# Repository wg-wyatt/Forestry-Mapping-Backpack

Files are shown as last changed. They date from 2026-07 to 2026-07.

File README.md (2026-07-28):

# Forestry Mapping Backpack

<table align="center" width="100%">
  <tr>
    <td align="center" valign="middle" width="50%">
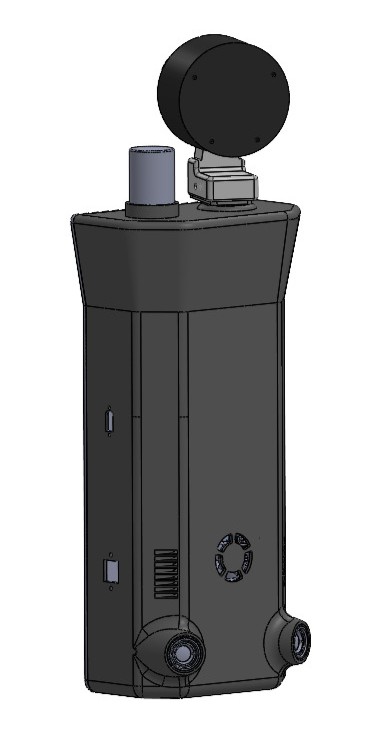
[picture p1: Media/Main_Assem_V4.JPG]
Forestry Mapping Backpack Exterior
      
      <br>
      <b>Exterior Assembly</b>
    </td>
    <td align="center" valign="middle" width="50%">
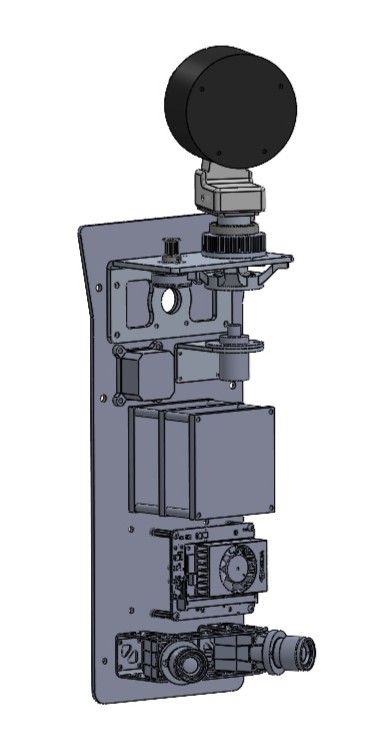
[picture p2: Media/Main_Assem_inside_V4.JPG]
Forestry Mapping Backpack Interior
      
      <br>
      <b>Interior Assembly</b>
    </td>
  </tr>
</table>

---

## Overview
The LiDAR Backpack Mapping System is a mobile, human-wearable sensing platform engineered to improve 3D point cloud density and spatial coverage for forestry and ecological surveying. Developed to replace rigid mast-mounted sensors, the system integrates a continuous secondary rotation axis with onboard processing to optimize sensor range, lower the user's center of gravity, and improve ergonomics during extended field deployment.

---

## Key Features

- Rotating LiDAR platform
- Integrated IMU for spatial orientation
- Modular mechanical architecture
- MATLAB analysis supporting point cloud generation
- Timing belt-driven rotation system
- Custom KiCad PCB
- FEA-validated structural design
- Optimized for low-volume manufacturing

### Project Disclaimer

This project was completed in collaboration with the Purdue Forestry Department. Certain project details, files, and implementation documentation may be limited due to sponsor requirements and intellectual property considerations.

---

## Problem Statement
The Purdue Forestry Department utilizes a machine learning–based plant recognition system to assist researchers with ecological surveying and vegetation analysis. Their legacy setup relied on a static LiDAR sensor mounted atop a tall backpack support mast. This configuration suffered from two major limitations:
* **Limited Spatial Coverage:** The static sensor depended entirely on natural user motion during field traversal to expand scan coverage, leading to low point cloud density and occlusions.
* **Poor Ergonomics:** Positioning significant mass high above the backpack shifted the system's center of gravity, reducing stability and user comfort during extended hiking over uneven terrain.

The objective of this project was to engineer a field-deployable mounting platform that adds a continuous secondary rotation axis to maximize point cloud density while relocating system mass closer to the user's center of gravity.

---

## Design Requirements

The following design requirements were established during the concept development phase to guide system architecture and engineering decisions. Requirements were selected to balance field usability, sensing performance, manufacturability, and compatibility with the existing Purdue Forestry Department backpack platform.

### Mechanical Requirements

| ID | Requirement | Target | Verification Method |
|----|---|---|---|
| DR-01 | Total system weight | < 10 kg (excluding backpack) | CAD mass properties |
| DR-02 | Structural durability | Withstand 5 g loading without structural failure | Finite Element Analysis (FEA) |
| DR-03 | Manufacturability | Components shall be manufacturable using conventional CNC machining, sheet metal fabrication, additive manufacturing, and commercially available hardware | Design review and manufacturing drawings |
| DR-04 | Serviceability | Electronics and wearable components shall be removable without permanent modification to the assembly | Assembly review |

### Functional Requirements

| ID | Requirement | Target | Verification Method |
|----|---|---|---|
| FR-01 | Point cloud coverage | Provide 360° scanning with a secondary axis of rotation to improve spatial coverage and reduce occlusions | MATLAB analysis and future field validation |
| FR-02 | Rotational position tracking | Report motor position to ±0.01° for point cloud reconstruction | Encoder specification and software verification |

### Integration Requirements

| ID | Requirement | Target | Verification Method |
|----|---|---|---|
| IR-01 | Backpack compatibility | Integrate with the existing Purdue Forestry backpack frame, 24 V hot-swappable M18 battery system, and existing data interfaces | CAD integration and electrical design review |
| IR-02 | Environmental protection | Minimum enclosure protection equivalent to IP32 | Enclosure design review and future ingress testing |

---

## System Architecture

The LiDAR Backpack Mapping System is a modular mechatronic platform structured into four core subsystems: **Sensing**, **Motion Control**, **Power Distribution**, and **Processing & Data**. 

<p align="center">
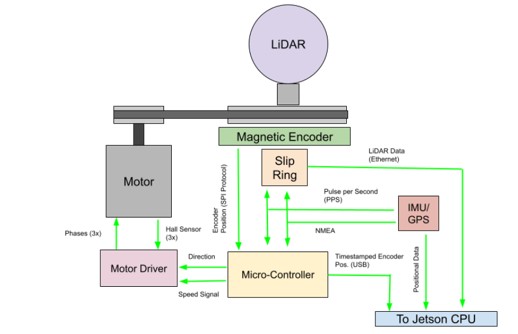
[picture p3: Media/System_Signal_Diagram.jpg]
System Diagram
  
</p>

### Sensing System
The sensing subsystem consists of an Ouster OS1 LiDAR sensor paired with an Ellipse N inertial measurement unit (IMU). The LiDAR provides high-resolution 3D measurements, while the IMU provides time synchronization and spatial orientation. Combining these inputs with rotational position feedback enables full point-cloud reconstruction.

### Motion Control System
The motion control subsystem provides controlled rotation of the LiDAR assembly via a motor-driven mechanism. A geared timing belt transmission ensures stable torque delivery, while encoder feedback tracks rotational position to synchronize scanning motion with sensor data.

### Power Distribution System
The system utilizes a 24 V hot-swappable battery architecture inherited from the base backpack platform. Dedicated regulation hardware distributes power safely to the LiDAR, motor controller, embedded electronics, and compute unit.

### Processing and Data System
An NVIDIA Jetson Orin platform serves as the central compute unit, handling data acquisition, sensor synchronization, and point-cloud generation. Communication protocols across all hardware are streamlined to minimize external cabling and maintain reliable data transfer.

---

## Mechanical Design

<table border="0" cellpadding="10" cellspacing="0" width="100%">
  <tr>
    <td width="40%" align="center" valign="middle">
      Forestry Mapping Backpack Full Assembly
    </td>
    <td width="60%" valign="middle">
      <p>The mechanical architecture focuses on a modular, field-serviceable platform designed to integrate all sub-assemblies while maintaining full compatibility with the host Purdue Forestry backpack frame. The physical layout prioritizes low system mass, protected cable routing, and high structural rigidity under dynamic motion.</p>
    </td>
  </tr>
</table>

### Rotational Drive System
A motor-driven timing belt transmission provides continuous rotation for the LiDAR assembly based on velocity parameters defined in MATLAB. A compact T2 timing belt system was selected for high torque transfer and reliable engagement using off-the-shelf hardware.

The drivetrain uses a 15-tooth driving pulley and a 75-tooth driven pulley to deliver a 5:1 reduction ratio. This reduction increases output torque to provide smooth, stable rotational motion across variable operating speeds.

### Structural Packaging & Integration
The frame and enclosure assemblies are structured to support the mechanical loads of the continuous rotation drive without requiring structural overhaul of the base backpack:
* **Drive Support Frame:** Provides a rigid mounting interface for the motor, bearing stack, and pulley system to maintain precise belt alignment and tension during dynamic motion.
* **Unified Component Enclosure:** Houses the compute, power regulation, and data acquisition hardware within a single physical module, allowing for seamless electrical integration between the motion system and the original architecture
* **Serviceable Assemblies:** Component layouts allow the drive assembly or processing housing to be accessed and serviced independently without full frame disassembly.

---

## Electrical Design

The electrical architecture was designed to integrate the LiDAR sensor, IMU, motor control system, embedded controller, and onboard processing hardware into the existing Purdue Forestry backpack platform. The design focused on maintaining compatibility with the legacy 24 V power system while providing reliable communication between sensing, motion, and processing subsystems.

<p align="center">
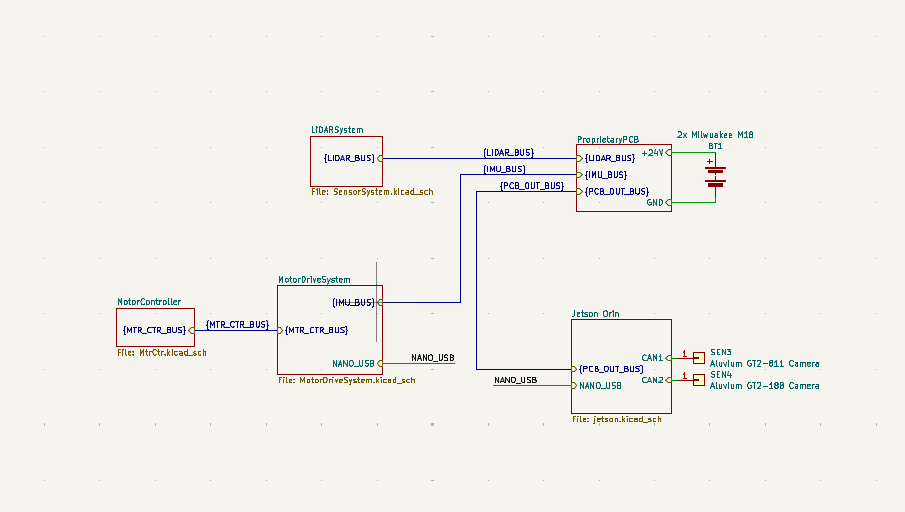
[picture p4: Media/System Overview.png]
System Overview Diagram
  
  <br>
  <em>System Overview Diagram</em>
</p>

### Drive System

The purpose of the design is to provide closed-loop control of the LiDAR rotation axis while maintaining reliable communication between the motion hardware and the onboard processing system.

<p align="center">
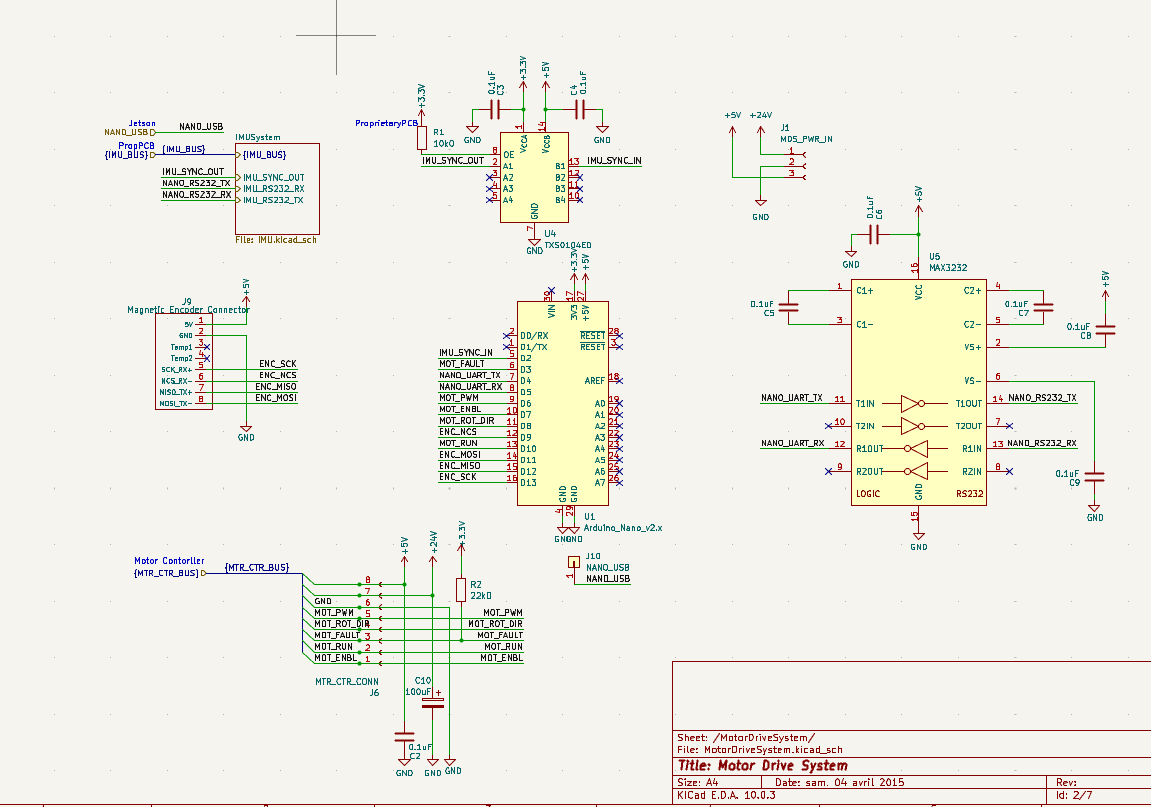
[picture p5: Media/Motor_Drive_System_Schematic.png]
Motor Drive System Schematic
  
  <br>
  <em>Motor Drive System Schematic</em>
</p>

The embedded controller communicates with the motor driver to provide rotational commands, including direction and speed control. The motor driver supplies the required power to the actuator while isolating the low-power control electronics from the higher-current motor circuit.

An encoder feedback system is integrated into the drive architecture to provide rotational position information. This feedback allows the system to monitor the actual motor position and provides the positional data required to synchronize the LiDAR scan with the mechanical rotation of the secondary axis.

The drive system architecture consists of:

- **Embedded controller:** Generates motion commands and manages communication with the motor driver and feedback devices.
- **Motor driver:** Converts low-power control signals into the required motor power output.
- **Motor and encoder:** Provide rotational actuation and position feedback for closed-loop monitoring.

The schematic was developed to separate power, control, and feedback signals, improving system organization and simplifying future troubleshooting, fabrication, and integration.

### PCB Design

A custom PCB was developed to consolidate system interfaces and simplify integration between the embedded controller, sensors, and external hardware. The board provides organized connections for power, communication, and control signals while reducing wiring complexity compared to a fully discrete implementation.

Future revisions would integrate additional functionality into a single consolidated interface board to further improve reliability, manufacturability, and ease of assembly.

<p align="center">
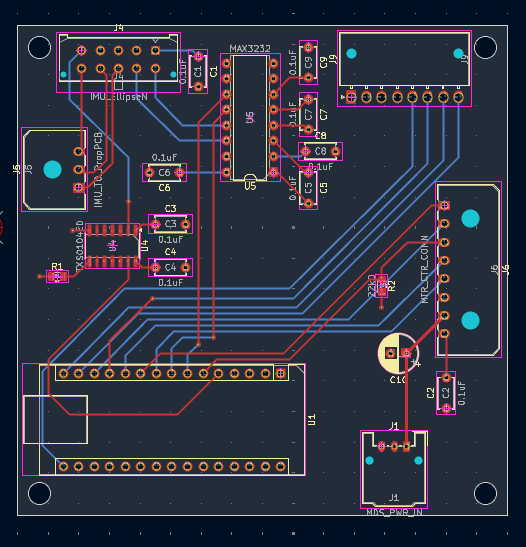
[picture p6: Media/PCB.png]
Custom PCB Layout
  
  <br>
  <em>Custom interface board routing and connector layout</em>
</p>

<p align="center">
  📂 <strong><a href="Electronics">View Schematic & Board Layout Files (Electronics Folder)</a></strong>
</p>

---

## System Software & Embedded Controls

The system utilizes an NVIDIA Jetson Orin Nano onboard compute module running custom proprietary software to process incoming sensor streams, generate real-time 3D point clouds, and execute plant species identification algorithms. Working in tandem with the primary compute, an embedded microcontroller manages closed-loop motor dynamics, sensor data acquisition, and precise timestamping:

* **Embedded Speed Control:** Interfaces directly with motor Hall effect sensors via the motor controller to provide closed-loop control. The motor operates at **35 Hz** to drive the geared transmission, maintaining the secondary axis LiDAR rotation at a continuous, stable **7 Hz**.
* **Encoder & IMU Data Processing:** Processes quadrature encoder data for real-time rotational position tracking while timestamping high-rate IMU telemetry to ensure precise spatial orientation and point cloud time synchronization.
* **Pipeline Processing:** Synchronizes raw LiDAR packet streams with orientation data, applying coordinate transformations and noise filtering to export uniform, high-density point cloud files (`.ply` / `.pcd`) ready for forestry canopy analysis.

📂 **[View Embedded System Firmware (Complete_Code.ino)](Analysis%20%26%20Code/Complete_Code/Complete_Code.ino)**

---

## LiDAR Coverage Analysis

Engineering analysis was used to establish design parameters and validate critical system decisions. The analysis process began by evaluating the relationship between LiDAR measurement characteristics and scanning motion, which informed the required rotational velocity of the system. Mechanical drive calculations were then performed to select an appropriate transmission design, followed by structural analysis of the final assembly.

### MATLAB Scanning Analysis
A MATLAB model was developed to simulate the point cloud generated by a LiDAR unit rotating about two independent axes. The objective of the analysis was to determine the external rotational frequency required to achieve complete and uniform point cloud coverage from a stationary position.

The LiDAR's internal emitter operates at a rotational frequency of 10 Hz. Because the LiDAR was mounted on a secondary rotating axis, the relationship between the internal scan frequency and the external rotational frequency directly influences point cloud density and spatial coverage. Selecting an external rotational frequency that is an integer factor or multiple of the internal 10 Hz scan frequency results in periodic overlap of the scan pattern, producing incomplete coverage and gaps within the reconstructed point cloud.

Multiple external rotational frequencies were evaluated using the MATLAB model. Simulation results demonstrated that secondary axis rotational frequencies of **3 Hz** and **7 Hz** produced the most uniform point cloud distribution while minimizing repeated scan paths. Based on these results, the external rotational speed requirement for the mechanical drive system was established.

<p align="center">
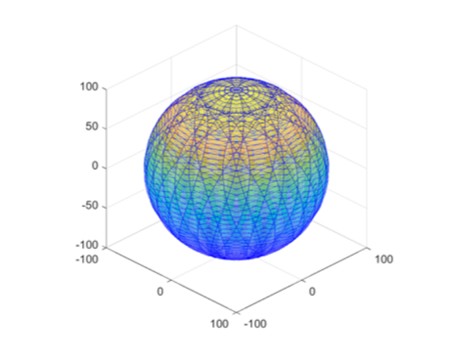
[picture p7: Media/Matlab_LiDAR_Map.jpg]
MATLAB LiDAR Point Cloud Coverage Simulation
  
  <br>
  <em>MATLAB Simulation showing point cloud coverage density over a 360-degree sweep at a 2.0 RPM target secondary axis speed</em>
</p>

The complete simulation script used to model the scanning spatial density can be accessed here:
👉 **[LiDAR_CoverageArea.m](Analysis%20%26%20Code/LiDAR_CoverageArea.m)**

### Rotation System and Gear Design

The rotational drive system was developed to achieve the operating speed established through the MATLAB analysis while maintaining reliable torque transmission and compact packaging.

A T2 timing belt was selected to provide positive, slip-free torque transmission between the motor and the rotating LiDAR assembly. Manufacturer design recommendations from MiSUMi were used during transmission selection, including a maximum recommended reduction ratio of **5:1** and a minimum pinion tooth engagement greater than six teeth. A 2 mm pitch timing belt was selected because it is commonly used in high-precision, low-speed motion systems and is readily available as a commercial component.

Using the selected pinion gear, the driven pulley diameter, tooth count, center-to-center pulley spacing, and timing belt length were analytically determined to satisfy both the required reduction ratio and packaging constraints.

Once the drivetrain geometry was established, the rotating assembly was modeled to estimate its mass moment of inertia. The driven pulley was approximated as a solid cylinder, while the LiDAR assembly was modeled as a rotating mass about the same axis. These values were used to calculate the torque required to accelerate the system to its operating speed within the desired startup time.

The calculated rotational speed and torque requirements were compared against the selected motor specifications to verify that the drivetrain would operate within the manufacturer's recommended operating range.

<p align="center">
  📂 <strong><a href="Analysis%20%26%20Code/GearSystemCalc.pdf">View Gear System Calculations (GearSystemCalc.docx)</a></strong>
</p>

## Structural & Dynamic Analysis (FEA)

Finite element analysis (FEA) was performed to evaluate the structural integrity and dynamic response of the redesigned LiDAR backpack assembly under operational shock and vibration conditions. 

<p align="center">
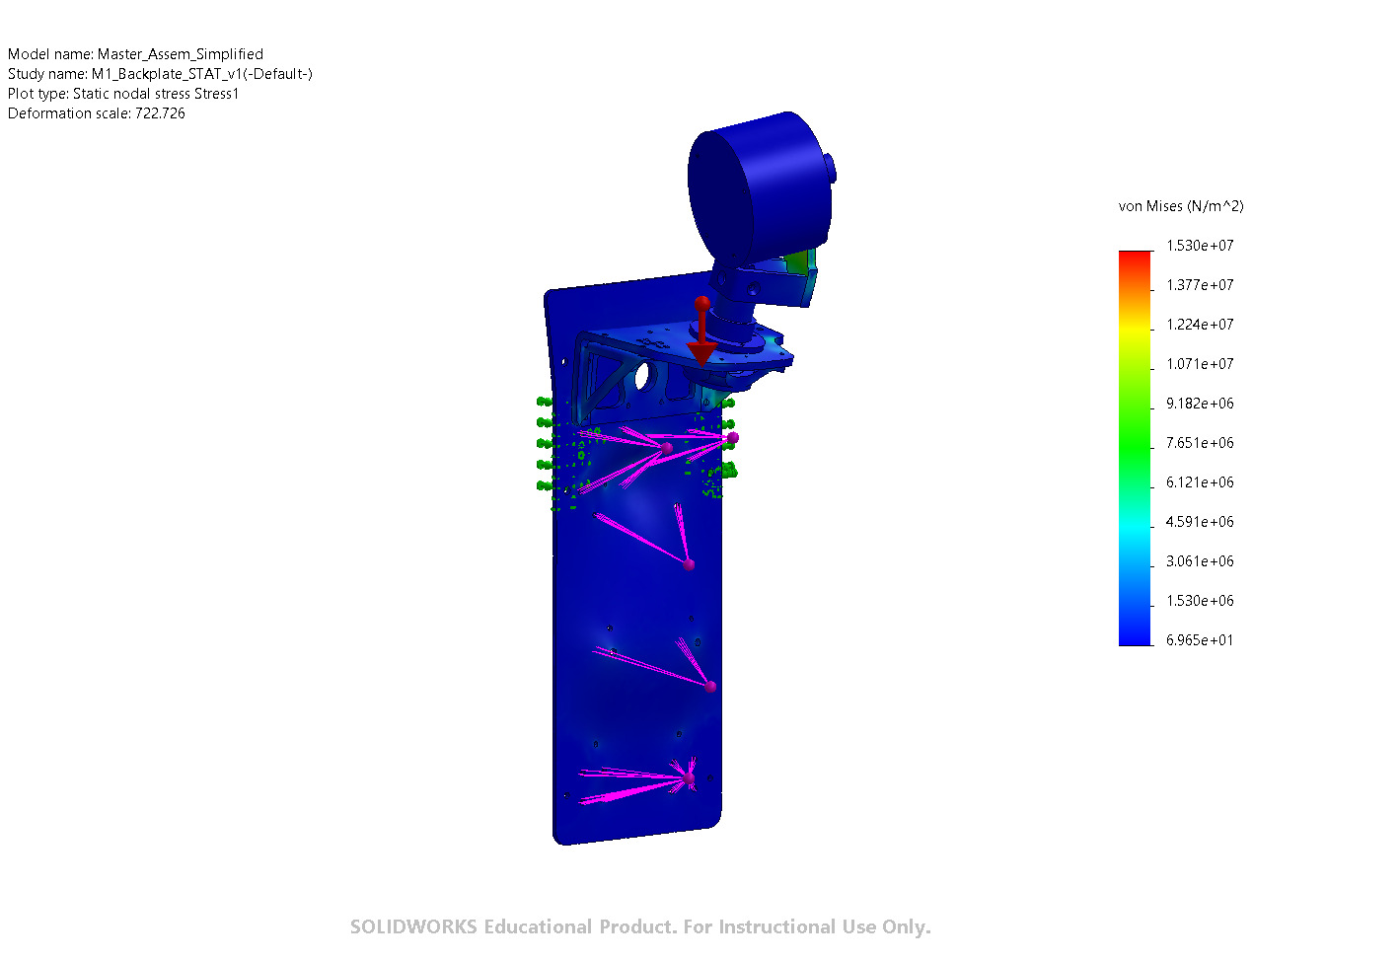
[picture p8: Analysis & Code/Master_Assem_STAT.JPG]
Full Assembly Static Loading FEA
  
  <br>
  <em>Full Assembly Static Stress Distribution (5 g Inertial Shock Load)</em>
</p>

### Static Structural Analysis
A uniform **5 g inertial shock acceleration** was applied to evaluate structural yield margins during field transport. Component materials were modeled as linear elastic, with sheet metal structures utilizing shell or solid elements based on section thickness. Non-structural electronics were represented as equivalent point masses to maintain accurate inertial loading while optimizing solver performance.

<div align="center">

| Assembly / Component | Max Displacement | Max Von Mises Stress | Factor of Safety (FoS) |
| :--- | :---: | :---: | :---: |
| **LiDAR Mounting Bracket** | 0.044 mm | 13.42 MPa | 20.62 |
| **Motor Bracket Assembly** | 0.048 mm | 13.00 MPa | 4.95 |
| **Full Structural Assembly** | 0.085 mm | 15.30 MPa | 4.27 |

</div>

* **Structural Integrity:** The carbon fiber backplate and aluminum mounting hardware maintain significant structural margin under 5 g shock conditions, exceeding yield safety factor requirements with a minimum assembly FoS of **4.27x**.
* **Deflection Limits:** Maximum full-assembly displacement is constrained to **0.085 mm**, maintaining precise positional stability for high-accuracy point cloud generation.

---

### Modal Frequency Analysis
Modal analysis was performed to identify assembly natural frequencies and prevent forced resonance with primary system excitation sources (LiDAR internal sweep at 10 Hz, secondary axis at 7 Hz, and drive motor rotation at 35 Hz).

<p align="center">
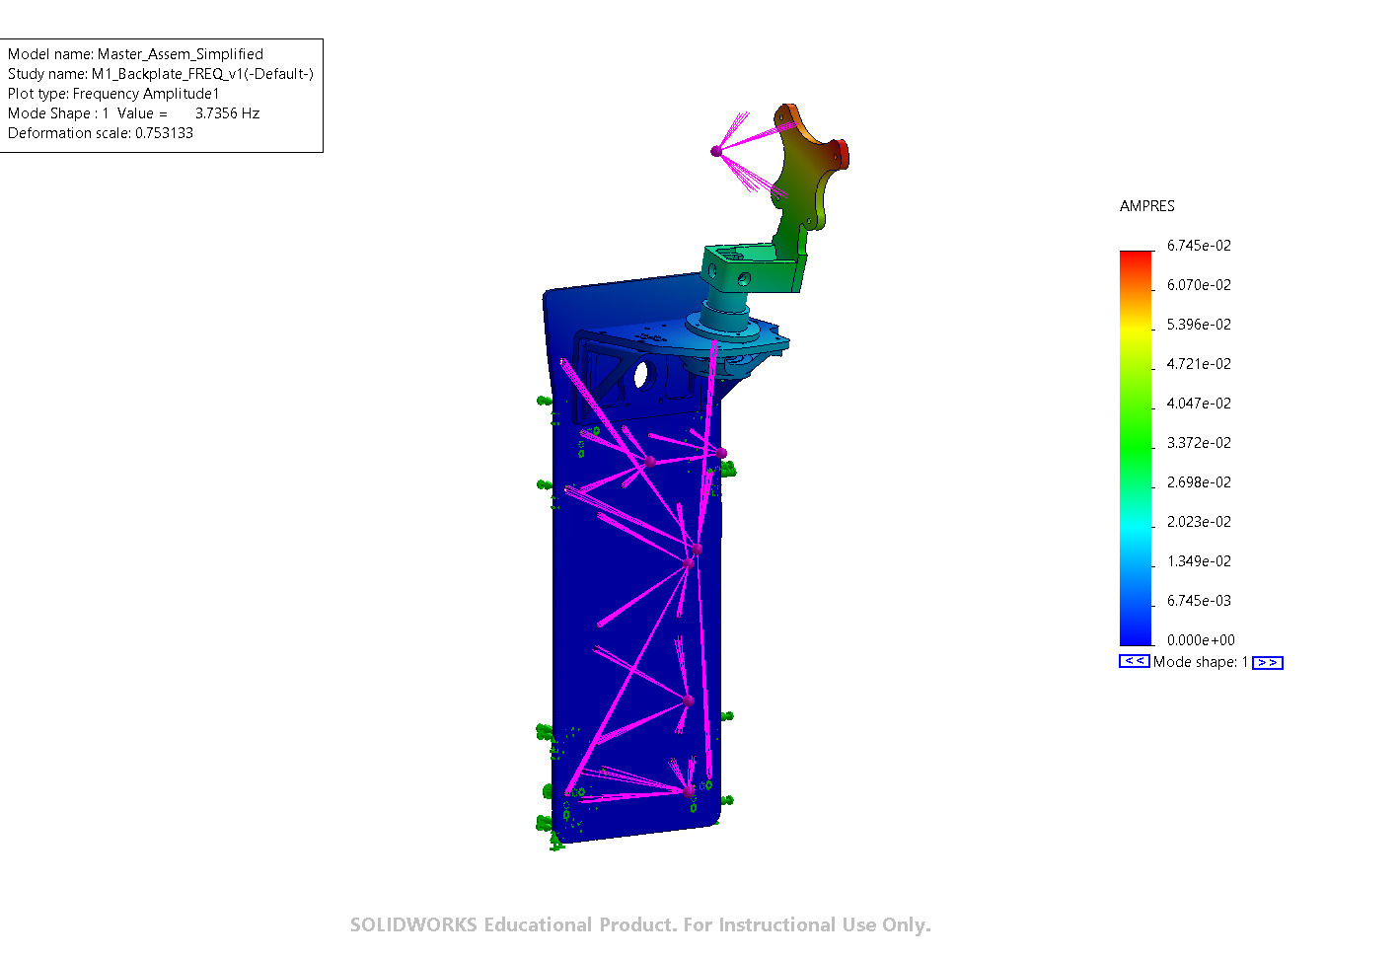
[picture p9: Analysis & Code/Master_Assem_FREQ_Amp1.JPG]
Full Assembly Modal Analysis
  
  <br>
  <em>Primary Assembly Mode Shape (3.77 Hz Fundamental Frequency)</em>
</p>

<div align="center">

| Mode | Natural Frequency (Hz) | Dynamic Mode Behavior |
| :---: | :---: | :--- |
| **1** | 3.77 Hz | Global oscillation of LiDAR assembly relative to backplate |
| **2** | 4.77 Hz | Torsional and lateral assembly deflection |
| **3** | 11.52 Hz | Secondary structural bending mode |
| **4** | 72.41 Hz | High-frequency backplate bending |
| **5** | 80.81 Hz | Localized bracket structural mode |

</div>

* **Resonance Avoidance:** System modal frequencies successfully clear the primary operating frequencies of the rotating LiDAR (10 Hz) and drive motor (35 Hz), significantly reducing the risk of operational resonance during scanning.
* **Global Dynamic Behavior:** While the fundamental natural frequency (3.77 Hz) lies near human walking cadence (1.5–2.5 Hz and harmonics), localized stiffening modifications (such as motor bracket gussets) produced minimal frequency shifts. This demonstrates that strain energy is distributed globally across the structure, with overall dynamic behavior governed by global mass distribution and system geometry rather than local stiffness.*

---

## Design for Manufacturing

The LiDAR Backpack Mapping System was designed with low-volume fabrication in mind. While the system was developed as a research prototype, the mechanical architecture prioritized manufacturability, accessibility of components, and ease of assembly using processes available to small-scale fabrication shops.

### Manufacturing Approach

The design utilizes a combination of conventional manufacturing methods, including CNC machining, sheet metal fabrication, additive manufacturing, and commercially available hardware. Manufacturing processes were selected based on part function, required precision, and cost considerations.

Critical structural and alignment features were designed around machinable interfaces, while non-critical components were designed to reduce manufacturing complexity and allow rapid iteration.

### Component Selection

Commercially available components were incorporated where possible to reduce custom fabrication requirements. Examples include:

- Timing belt and pulley components
- Bearings
- Fasteners
- Motor and encoder hardware
- Electrical connectors

Using standardized components reduces lead times, simplifies replacement, and improves long-term serviceability.

### Assembly and Serviceability

The system was designed as a modular assembly with separate mechanical, electrical, and sensing components. This approach allows individual subsystems to be accessed, replaced, or modified without requiring complete disassembly of the platform.

Design considerations included:

- Accessible fasteners
- Modular enclosure design
- Cable routing considerations
- Separation of structural and electronic components

### Future Manufacturing Considerations

If transitioned from prototype design to production, additional engineering documentation would be developed, including detailed manufacturing drawings, tolerance specifications, and GD&T on critical interfaces.

Potential future manufacturing validation would include:

- Fabrication of prototype components
- Assembly verification
- Dimensional inspection
- Structural testing

---

## Project Status

The LiDAR Backpack Mapping System was developed as part of a senior design project in collaboration with the Purdue Forestry Department. The project progressed through multiple design iterations, beginning with the development of a benchmark system and continuing toward a fully integrated field-deployable platform.

### Benchmark System

An initial benchmark system was developed by the senior design team to provide a functional platform for evaluating the plant recognition workflow. This system utilized lower-grade electronics and a simplified mounting approach that allowed it to be installed on the existing backpack platform.

The benchmark system established a baseline hardware configuration and provided a foundation for future development. Further validation of the benchmark system with the plant recognition algorithm is planned.

### Integrated System Design

The current iteration focuses on integrating the complete sensing, motion, power, and processing architecture into a single manufacturable platform. The detailed design phase has been completed, including:

- Mechanical system design
- Sensor and hardware integration
- Electrical architecture development
- Motion system analysis
- MATLAB-based scanning analysis
- Manufacturing considerations

The system is currently at the fabrication-ready stage. Fabrication and physical validation will proceed upon sponsor approval and project continuation.

---

## Future Work

The next phase of development would focus on fabrication, system integration, and validation of the completed design. Future work would transition the system from a fabrication-ready design into a fully tested field deployment platform.

### Prototype Fabrication and Integration

Future work would begin with fabrication and assembly of the redesigned LiDAR platform. This phase would include the integration of the mechanical assembly, electrical hardware, sensing components, and onboard processing system.

Planned integration tasks include:

- Fabrication of mechanical components
- Assembly of the rotating LiDAR mechanism
- Integration of sensors, motor controller, and electronics
- Verification of mechanical and electrical interfaces

#### Mechanical Validation

Testing would include:

- **Weight validation:** Confirm total system mass meets the design requirement.
- **Drop testing:** Evaluate structural durability and ensure components remain functional after accidental impacts.
- **Backpack mobility testing:** Evaluate system usability during normal hiking conditions and verify that the updated mounting configuration improves integration with the backpack platform.

#### Environmental Validation

The enclosure and hardware protection would be evaluated through:

- Weather exposure testing
- Verification of enclosure protection against environmental conditions
- Confirmation that internal electronics remain protected during field operation

#### Data Collection and Algorithm Validation

The sensing system would be evaluated through field data collection tests, including:

- **Wall test:** Walking the backpack along a controlled surface to evaluate point cloud consistency and rotational accuracy.
- Validation of LiDAR point cloud generation with the plant recognition algorithm.
- Evaluation of sensor synchronization and positional tracking accuracy.

#### Electrical Validation

Electrical integration testing would verify:

- Stable power delivery from the existing 24 V battery system
- Reliable communication between sensors, motor controller, and processing hardware
- Continuous operation of the motor and sensing systems during data collection

### Future Hardware Improvements

Additional hardware improvements identified during the design process include:

- Replacing the Arduino Nano-based control system with an STM32 microcontroller to improve processing capability, communication flexibility, and future expandability.
- Consolidating the current distributed PCB architecture into a single integrated interface board to reduce wiring complexity, improve reliability, and simplify assembly.

---

## Skills Demonstrated

### Mechanical Design
- SolidWorks CAD modeling and assembly design
- Mechanical packaging and system integration
- Timing belt transmission design and gear ratio calculations
- Structural design considerations for field-deployed hardware
- Design for manufacturing (CNC machining, sheet metal fabrication, additive manufacturing)
- Modular assembly and serviceability considerations

### Electrical and Embedded Systems
- System-level electrical architecture development
- Power distribution and hardware integration
- Sensor and actuator interfacing
- PCB system design using KiCad
- Embedded controller integration and communication planning

### Engineering Analysis
- MATLAB-based system modeling and scanning analysis
- Rotational velocity optimization
- Mechanical drivetrain calculations
- Torque and load analysis
- Finite Element Analysis 

### Engineering Tools
- SolidWorks
- KiCad
- MATLAB
- Python
- Technical documentation
  
---

## Acknowledgments

This project was completed in collaboration with the Purdue Forestry Department as part of a senior design project focused on improving field deployment of plant recognition and LiDAR mapping systems.

Special thanks to **Evan Flatt, Purdue Forestry Department**, for sponsoring the project, providing the application requirements, domain knowledge, and guidance that informed the system design.

The initial benchmark platform was developed from an existing legacy system and served as the foundation for subsequent design iterations. The integrated LiDAR mapping platform presented in this portfolio represents the continued development of that system, including the mechanical redesign, system architecture, drivetrain analysis, and integration planning.

Additional contributions from team members are acknowledged where applicable, including assistance with software development and specific CAD contributions.

---

## References

<p align="center">
  
</p>

<blockquote>
  <p align="center">
    <strong>📚 Academic & Technical References coming soon.</strong><br>
    Currently compiling literature on LiDAR spatial mapping algorithms, 2D-to-3D point cloud reconstruction math, and academic papers on forestry canopy density measurement standards.
  </p>
</blockquote>

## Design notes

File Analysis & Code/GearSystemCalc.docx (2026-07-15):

# Gear System Hand Calculations

Assumptions

- At least 6 teeth must be engaged with the belt at all times (Nengaged>6)
- The gear ratio should be lower than 5:1
- Timing belt transmits torque instantaneously; thus pinion torque is a function of driven gear torque and gear ratio
- Driven gear is modeled as cylinder for inertia calculations
- LiDAR unit is modeled as shaft for inertia calculations

Diagram

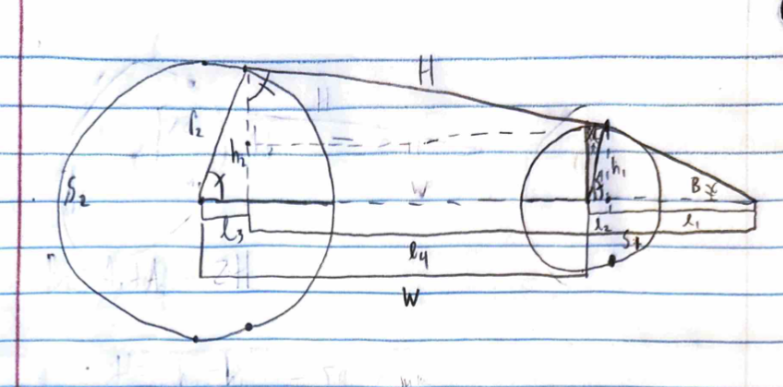
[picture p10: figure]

Figure J1. Hand Sketch of Gear Geometry

Calculations

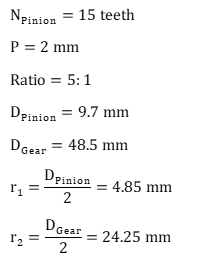
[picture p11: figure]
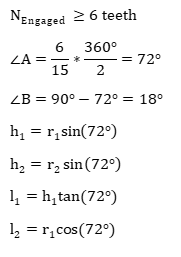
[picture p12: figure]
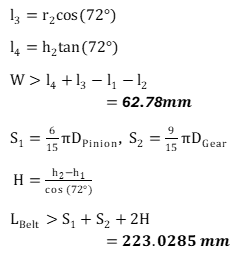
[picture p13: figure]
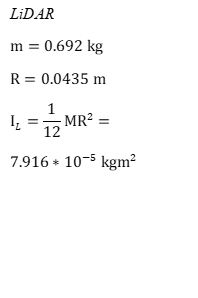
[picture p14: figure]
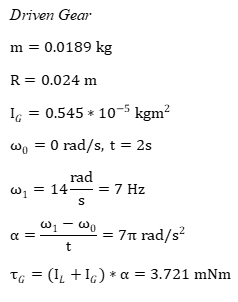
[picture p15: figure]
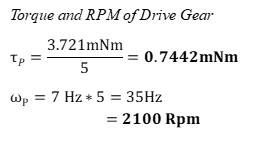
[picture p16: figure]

s

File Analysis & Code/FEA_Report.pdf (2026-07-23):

# Forestry Backpack FEA Report

## Purpose

Finite element analysis (FEA) was performed to verify the structural integrity and dynamic performance of the redesigned LiDAR backpack assembly. Static analyses were conducted to evaluate the strength and stiffness of the primary load-bearing components under the project sponsor's specified 5 g loading condition. Modal analyses were performed to identify the assembly's natural frequencies and assess the potential for resonance with the operating frequencies of the rotating LiDAR system.

## Assumptions

The following assumptions were made during the analysis:

- Fasteners were assumed to possess greater strength than the surrounding structural components and were therefore modeled using bonded connections rather than explicit bolt representations.
- The backpack mounting interface was represented by fixed boundary conditions applied to the mounting pad locations, approximating attachment to the existing backpack frame.
- Non-structural electronic components (motor controller, Jetson computer, printed circuit boards, cameras, and slip ring) were represented by their equivalent masses to accurately capture inertial loading while minimizing computational complexity.
- The carbon fiber backplate was modeled as an equivalent isotropic material. This simplification was adopted to improve solver stability while providing a reasonable approximation of the global structural response.
- Linear elastic material behavior was assumed for all components.
- Static loading was represented by a uniform 5 g inertial acceleration as specified by the project sponsor.
- Sheet metal components were modeled using both shells and solid geometry depending on material thickness and appropriate simplifications.

## Mesh

A curvature-based mesh with automatic local refinement was used for all analyses. This meshing approach provides improved resolution around holes, fillets, and other geometric transitions while maintaining a manageable element count. Because the objective was to evaluate global structural behavior and identify critical stress locations, this mesh was considered sufficient without additional local refinement.

## Results

### Static Structural Analysis

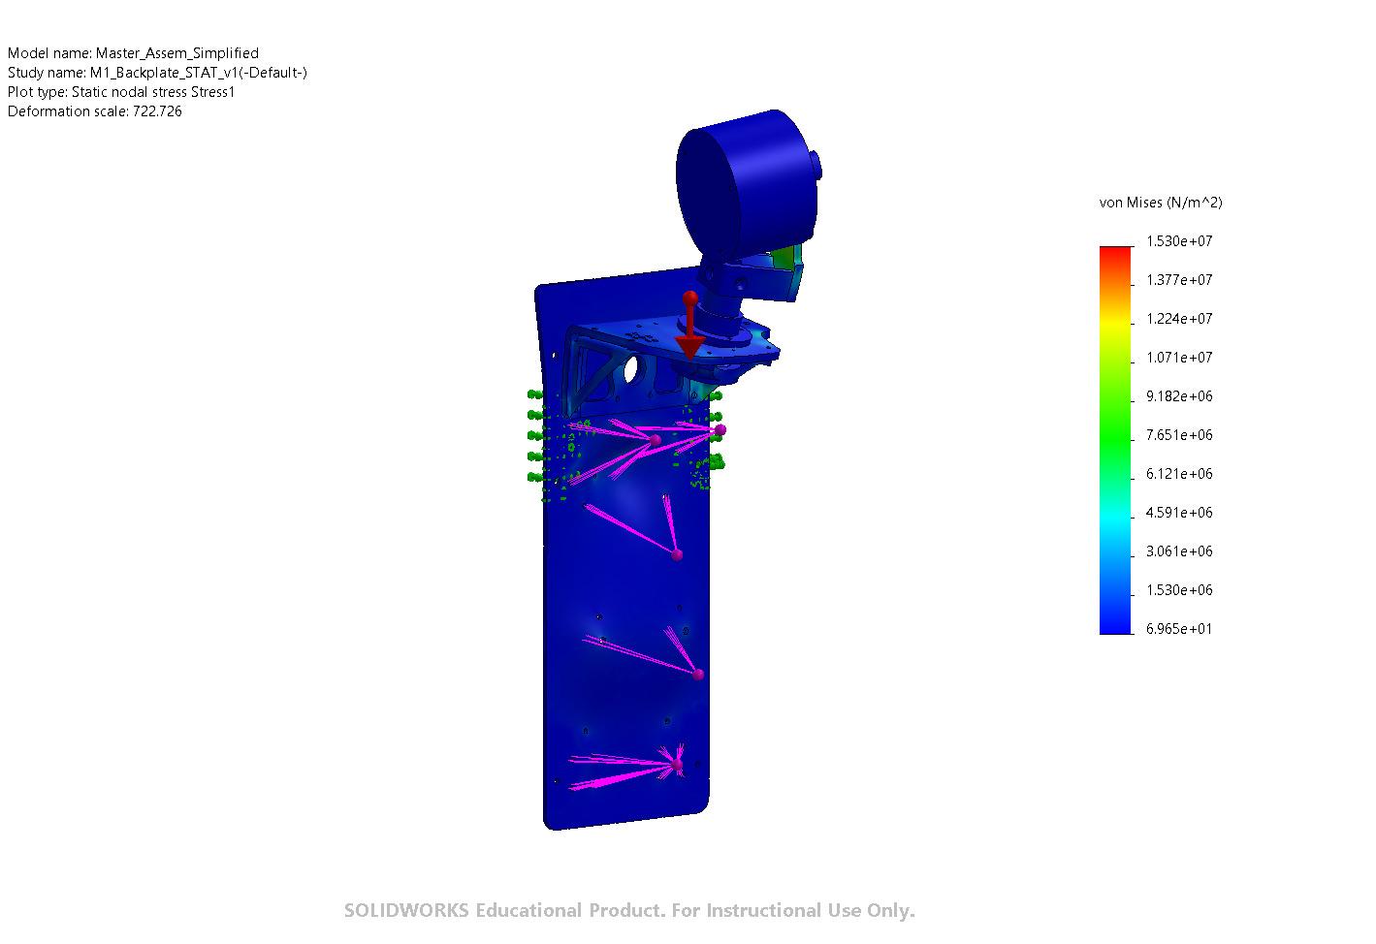
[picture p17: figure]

Figure 1. Full Assembly Static Loading

LiDAR Mounting Bracket
Table 1. LiDAR Mounting Bracket Static Results
Metric | Result
Maximum Displacement | 0.044 mm
Maximum Von Mises Stress | 13.42 MPa
Factor of Safety | 20.62

Impact:
The LiDAR mounting bracket remained within acceptable stress limits under the prescribed shock loading condition. Maximum displacement at the LiDAR mounting interface was limited to 0.044 mm, maintaining the positional stability required for LiDAR data collection.

Motor Bracket Assembly
Table 2. Motor Bracket Assembly Static Results
Metric | Result
Maximum displacement | 0.048 mm
Maximum Von Mises stress | 13.00 MPa
Factor of Safety | 4.95

Impact:
The motor bracket assembly maintained structural integrity under the 5 g loading condition. The analysis confirmed that the bracket geometry and mounting configuration provide sufficient strength to support the rotating LiDAR assembly.

Full Assembly

Table 3. Full Assembly Static Results
Metric | Result
Maximum displacement | 0.085 mm
Maximum Von Mises stress | 15.30 MPa
Factor of Safety | 4.27

Impact:
The carbon fiber backplate demonstrated sufficient stiffness and strength to support the redesigned LiDAR system. The maximum displacement remained within acceptable limits, indicating that the plate provides an appropriate structural foundation for the attached components.

### Modal Analysis

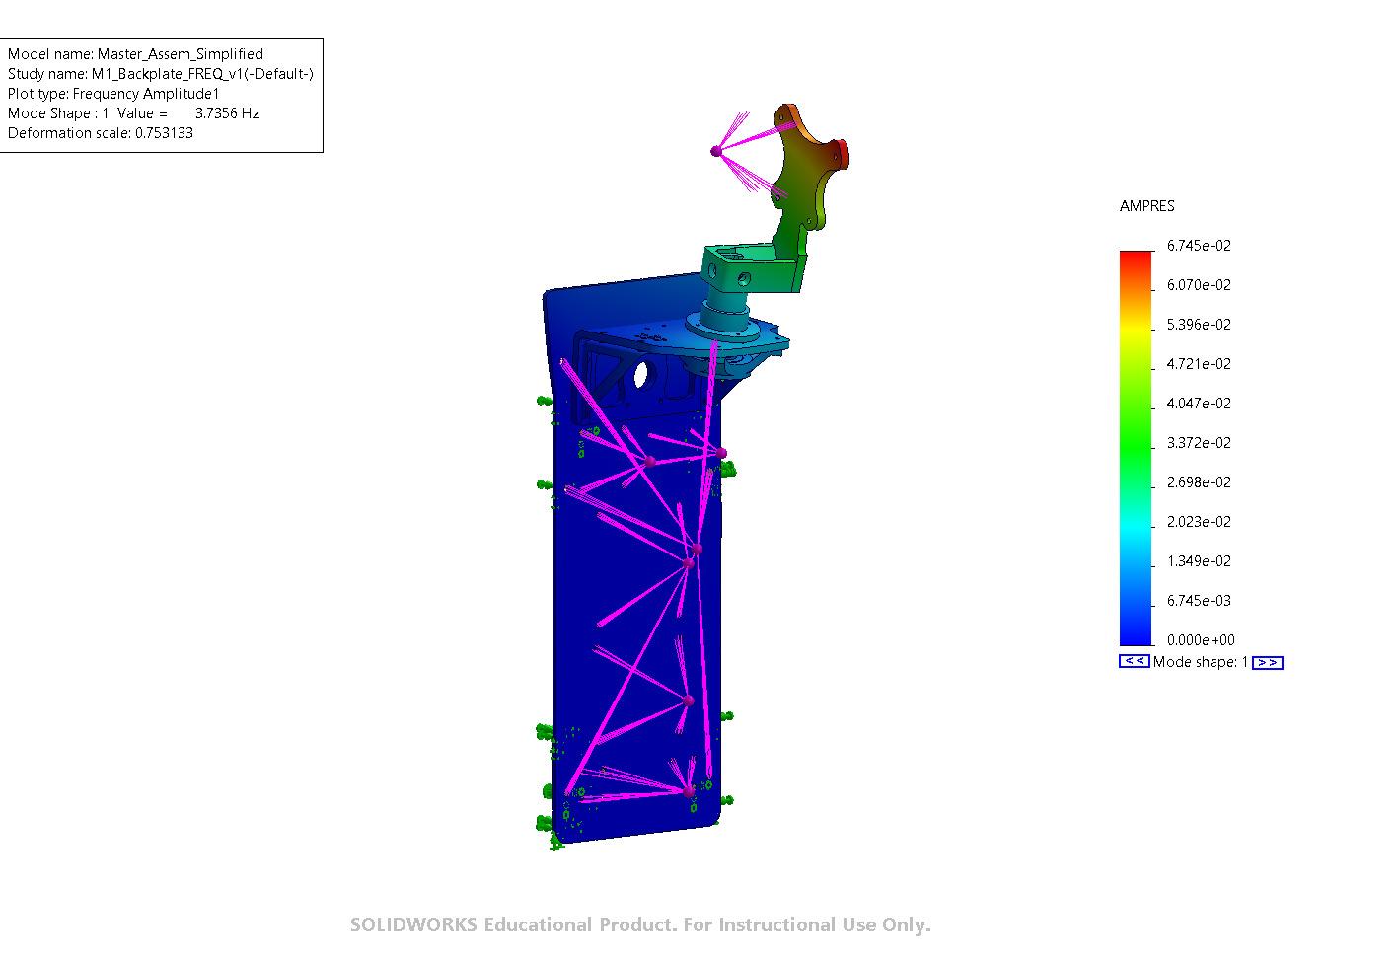
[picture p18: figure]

Figure 2. Full Assembly Modal Analysis

The natural frequencies of the assembled structure were evaluated to determine whether operational excitation frequencies could produce resonance. The first several modal frequencies are summarized below.
Table 4. Modal Frequencies
Mode | Natural Frequency (Hz)
1 | 3.7699
2 | 4.7698
3 | 11.538
4 | 72.415
5 | 80.852

The system's primary excitation frequencies are:

Table 5. Excitation Frequencies
Source | Frequencies (Hz)
LiDAR internal rotation | 10
Secondary LiDAR axis rotation | 7
Motor rotation | 35

Impact:
The modal analysis identified the lowest natural frequency within the range of human walking cadence, indicating a potential susceptibility to excitation from backpack motion and walking harmonics. However, the identified structural modes do not coincide with the primary operating frequencies of the LiDAR scanning system or motor, reducing the likelihood of resonance during normal operation. Additional local stiffening features, including gussets on the motor bracket, were evaluated but produced minimal frequency shifts. This occurs because the structural modes are broadly distributed across the entire assembly rather than localized to individual components, indicating that overall dynamic behavior is governed by global geometry and mass distribution rather than local stiffness.

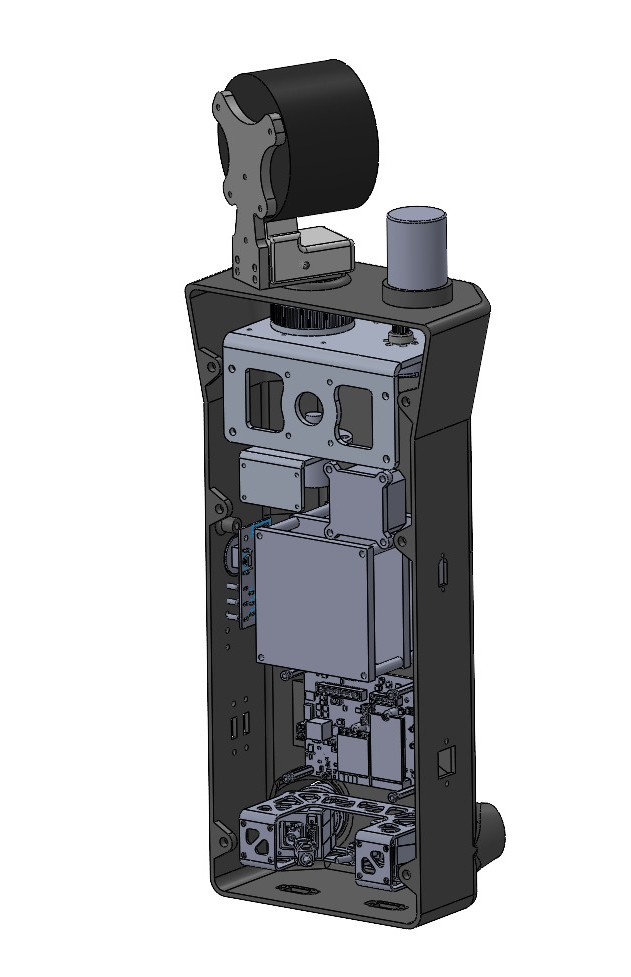
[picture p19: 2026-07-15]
Media/Main_Assem_rear.JPG

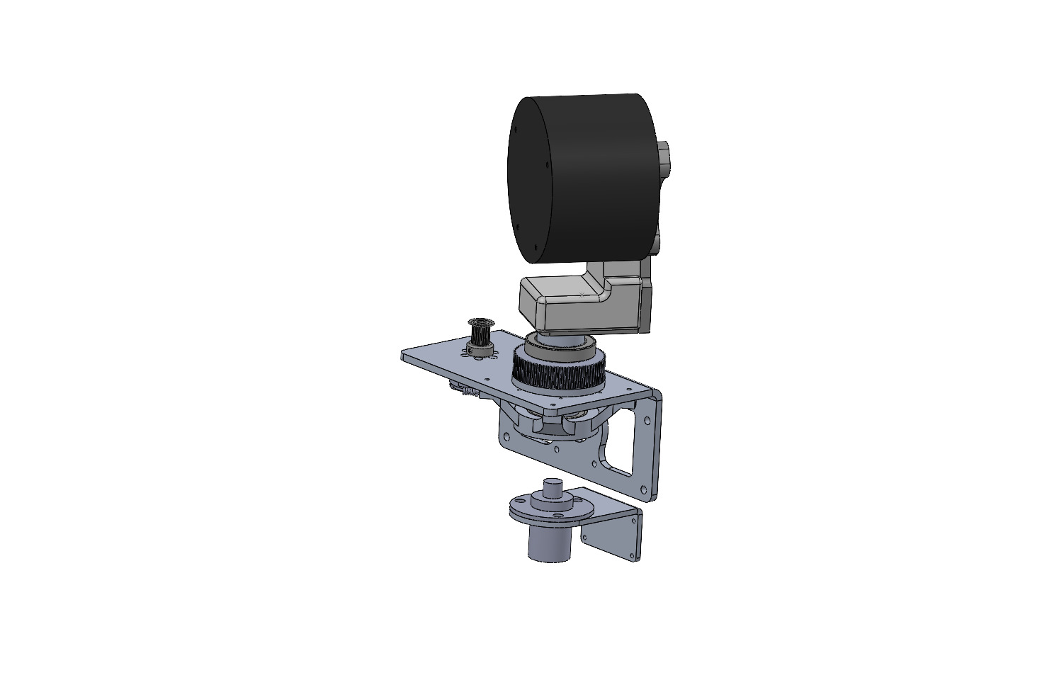
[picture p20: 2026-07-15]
Media/Mech_Drive_System.JPG

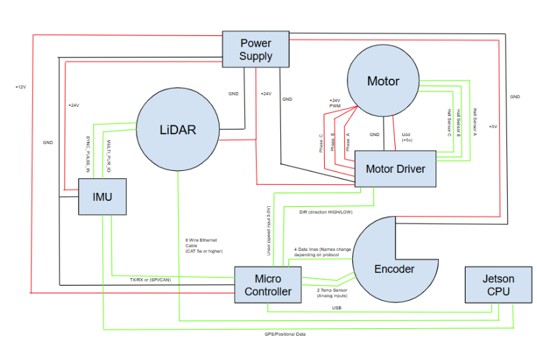
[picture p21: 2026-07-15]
Media/System_Power_Diagram.jpg

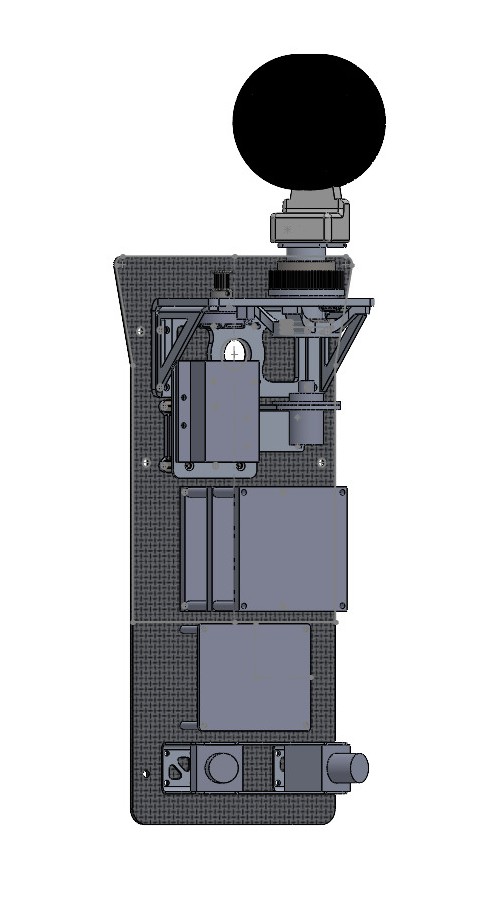
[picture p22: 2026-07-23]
Media/Main_Assem_inside_V5.JPG

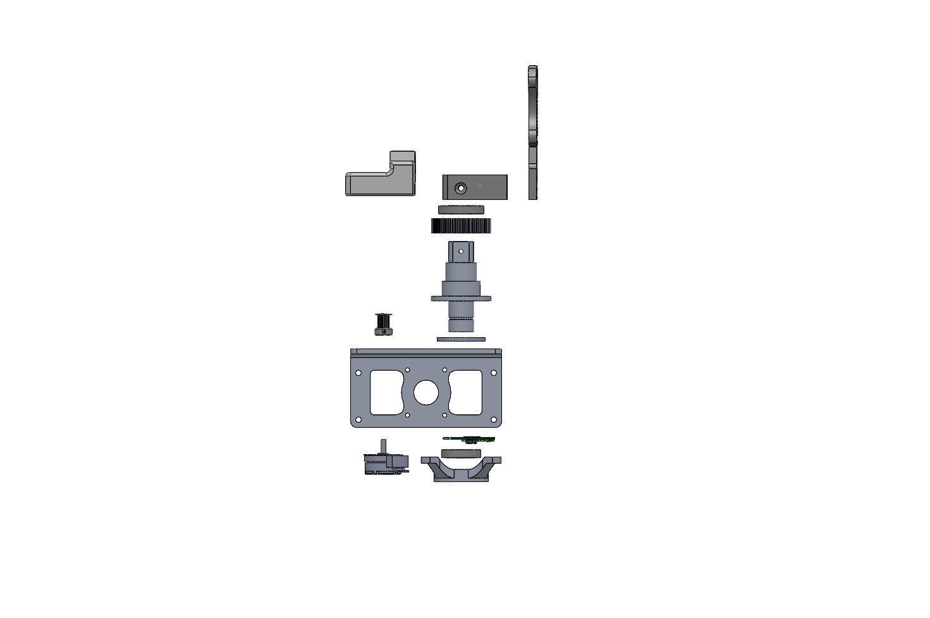
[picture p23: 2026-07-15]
Media/Mech_Drive_System_expl.JPG

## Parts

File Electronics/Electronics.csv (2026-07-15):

Reference | Value | Datasheet | Footprint | Qty | DNP
BT1 | 2x Milwuakee M18 |  |  | 1
C1,C11,C21,C22,C23 | 0.1uF |  |  | 5
C10 | 100uF |  |  | 1
C17,C18,C19,C20 | 1uF |  |  | 4
J1 | MagEncoder |  | Connector_Molex:Molex_CLIK-Mate_502382-0870_1x08-1MP_P1.25mm_Vertical | 1
J3 | Analog |  | Connector_PinHeader_2.54mm:PinHeader_1x15_P2.54mm_Vertical | 1
J4 | Digital |  | Connector_PinHeader_2.54mm:PinHeader_1x15_P2.54mm_Vertical | 1
J5,J10 | NANO_USB |  |  | 2
J7 | Conn_01x08_Socket |  | Connector_Molex:Molex_Micro-Fit_3.0_43045-0812_2x04_P3.00mm_Vertical | 1
J11 | CAM1 |  |  | 1
J12 | CAM2 |  |  | 1
J13 | GNSS_ANT |  |  | 1
MOT1 | FaulHaber_motor1 |  |  | 1
R1 | 10kO |  |  | 1
R2 | 22kO |  |  | 1
SEN1 | LiDAR_OS1 |  |  | 1
SEN2 | IMU_EllipseN |  | Connector_Molex:Molex_Micro-Fit_3.0_43045-1012_2x05_P3.00mm_Vertical | 1
SEN3 | Aluvium GT2-188 Camera,Aluvium GT2-811 Camera |  |  | 1
U2 | SC2804 Motor Controller |  |  | 1
U3 | Jetson Orin |  |  | 1
U4 | IMU_TO_PropPCB,TXS0104ED | www.ti.com/lit/ds/symlink/txs0104e.pdf | Connector_Molex:Molex_Micro-Fit_3.0_43045-0812_2x04_P3.00mm_Vertical,Package_SO:SOIC-14_3.9x8.7mm_P1.27mm | 1
U5 | MAX3232 | https://datasheets.maximintegrated.com/en/ds/MAX3222-MAX3241.pdf | Package_DIP:DIP-16_W7.62mm | 1

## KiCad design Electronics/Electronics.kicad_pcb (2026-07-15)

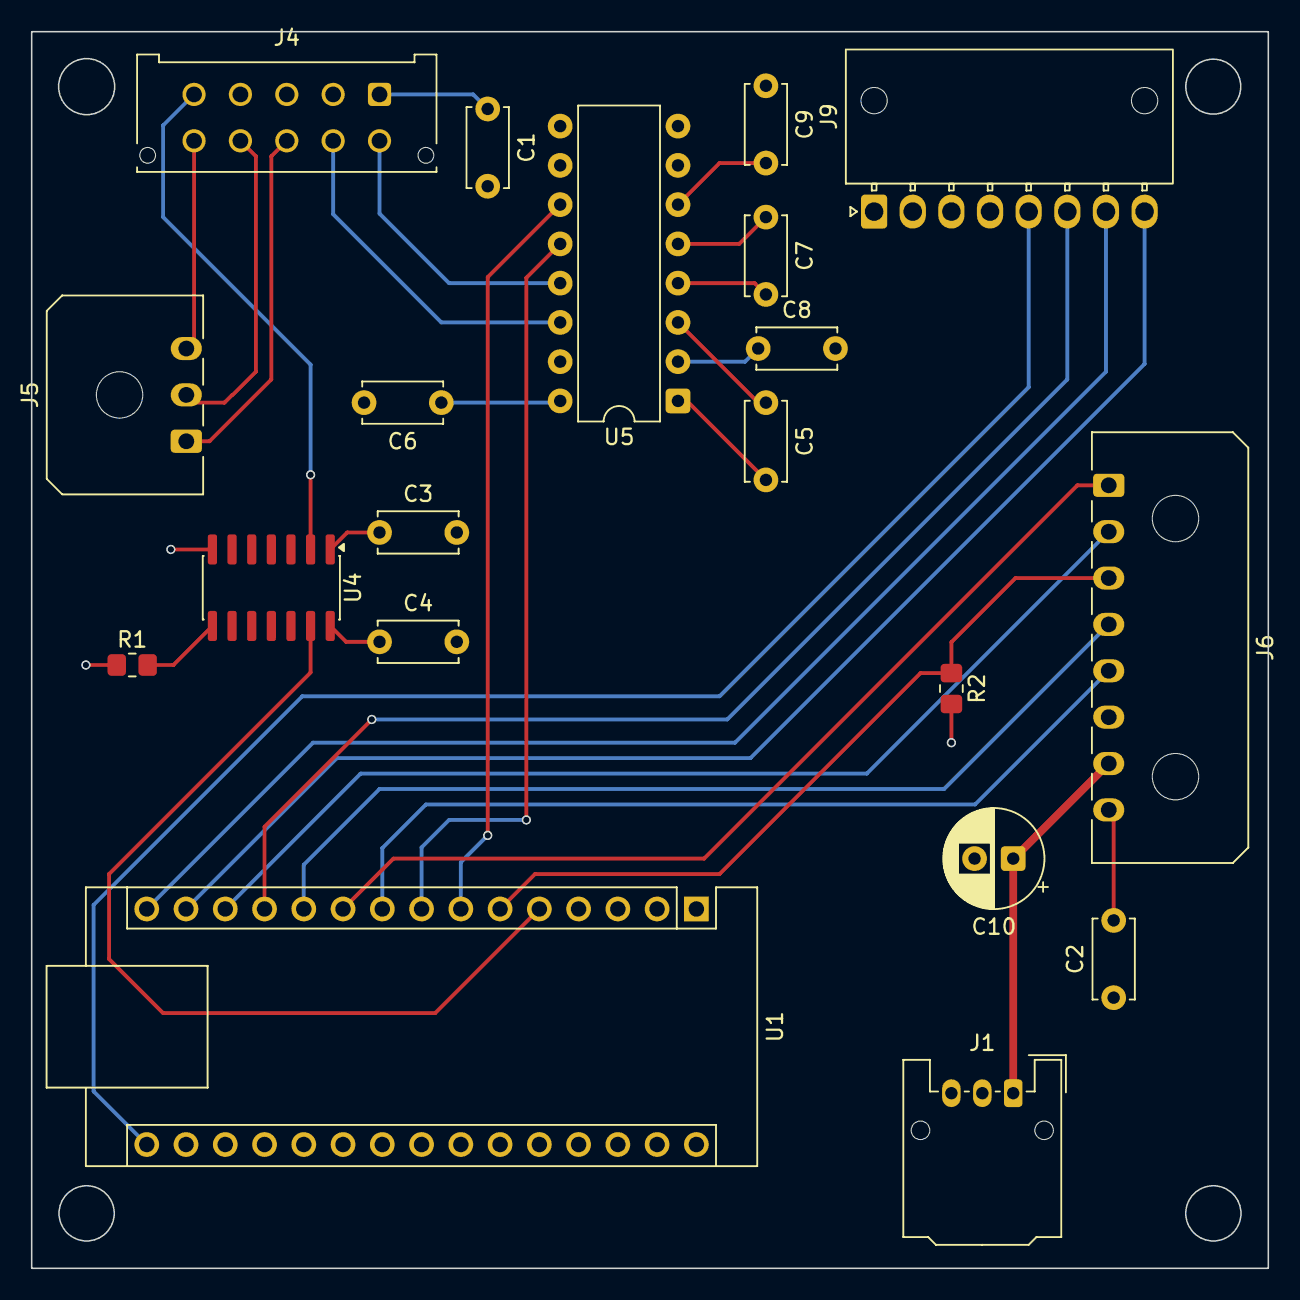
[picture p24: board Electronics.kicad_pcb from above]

Board: 6 copper layers, 80.0 x 80.0 mm, 20 parts (0 on the bottom side), 29 nets.

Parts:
C1, C2, C3, C4, C5, C6, C7, C8, C9: 0.1uF; C_Disc_D5.0mm_W2.5mm_P5.00mm
C10: 100uF; CP_Radial_D6.3mm_P2.50mm
J1: MDS_PWR_IN; Molex_MicroClasp_55935-0310_1x03_P2.00mm_Horizontal
J4: IMU_EllipseN; Molex_Micro-Fit_3.0_43045-1012_2x05_P3.00mm_Vertical
J5: IMU_TO_PropPCB; Molex_Micro-Fit_3.0_43650-0300_1x03_P3.00mm_Horizontal
J6: MTR_CTR_CONN; Molex_Micro-Fit_3.0_43650-0800_1x08_P3.00mm_Horizontal
J9: Magnetic Encoder Connector; Molex_Nano-Fit_105313-xx08_1x08_P2.50mm_Horizontal
R1: 10kO; R_0805_2012Metric_Pad1.20x1.40mm_HandSolder
R2: 22kO; R_0805_2012Metric_Pad1.20x1.40mm_HandSolder
U1: Arduino_Nano_v2.x; Arduino_Nano
U4: TXS0104ED; SOIC-14_3.9x8.7mm_P1.27mm
U5: MAX3232; DIP-16_W7.62mm

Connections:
+3.3V: C1.1, C3.1, J4.3 (Vin), R1.1, R2.2, U1.17 (3V3), U4.1 (V_{CCA})
+5V: C2.2, C4.1, C6.1, C8.2, J1.3, J6.8, J9.1 (5V), U1.27 (+5V), U4.14 (V_{CCB}), U5.16 (VCC)
+24V: C10.1, J1.1, J6.7
/IMU_RS422_RX: J4.10 (Port_B_RX), J5.3 (Port_E_RX)
/IMU_RS422_TX: J4.7 (Port_B_TX), J5.2 (Port_E_TX)
/IMU_SYNC_B: J4.2 (Sync_in_B), J5.1 (Sync_in_B)
/MOT_ENBL: J6.1, U1.10 (D7)
/MOT_FAULT: J6.3, R2.1, U1.6 (D3)
/MOT_PWM: J6.5, U1.9 (D6)
/MOT_ROT_DIR: J6.4, U1.11 (D8)
/MOT_RUN: J6.2, U1.13 (D10)
/MotorDriveSystem/ENC_MISO: J9.7 (MISO_TX+), U1.15 (D12)
/MotorDriveSystem/ENC_MOSI: J9.8 (MOSI_TX-), U1.14 (D11)
/MotorDriveSystem/ENC_NCS: J9.6 (NCS_RX-), U1.12 (D9)
/MotorDriveSystem/ENC_SCK: J9.5 (SCK_RX+), U1.16 (D13)
/MotorDriveSystem/IMU_SYNC_IN: U1.5 (D2), U4.13 (B1)
/MotorDriveSystem/IMU_SYNC_OUT: J4.6 (Sync_OUT), U4.2 (A1)
/MotorDriveSystem/NANO_RS232_RX: J4.8 (Port_A_TX), U5.13 (R1IN)
/MotorDriveSystem/NANO_RS232_TX: J4.9 (Port_A_RX), U5.14 (T1OUT)
/MotorDriveSystem/NANO_UART_RX: U1.8 (D5), U5.12 (R1OUT)
/MotorDriveSystem/NANO_UART_TX: U1.7 (D4), U5.11 (T1IN)
GND: C1.2, C2.1, C3.2, C4.2, C6.2, C9.1, C10.2, J1.2, J4.4 (GND), J6.6, J9.2 (GND), U1.4 (GND), U1.29 (GND), U4.7 (GND), U5.15 (GND)
unnamed: R1.2, U4.8 (OE)
unnamed: C5.2, U5.1 (C1+)
unnamed: C5.1, U5.3 (C1-)
unnamed: C7.2, U5.4 (C2+)
unnamed: C7.1, U5.5 (C2-)
unnamed: C8.1, U5.2 (VS+)
unnamed: C9.2, U5.6 (VS-)

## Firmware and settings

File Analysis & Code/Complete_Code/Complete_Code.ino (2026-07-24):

/**
 * @file main.cpp
 * @brief Motor Drive & IMU Synchronization System
 * 
 * @author Stefan Vin
 * @generated_with Gemini
 * @date 2026-07-23
 */
 
#include <TinyGPS++.h>
#include <SoftwareSerial.h>
#include <SPI.h>

// --- SCHEMATIC PIN DEFINITIONS ---
#define IMU_SYNC_PIN 2   // D2 - IMU_SYNC_IN (PPS / Time Sync Input)
#define MOT_FAULT_PIN 3  // D3 - MOT_FAULT (Input from Motor Controller)
#define IMU_RX_PIN    5  // D5 - NANO_UART_RX (From MAX3232 R1OUT)
#define IMU_TX_PIN    4  // D4 - NANO_UART_TX (To MAX3232 T1IN)
#define MOT_PWM_PIN   6  // D6 - MOT_PWM (Speed Control)
#define MOT_ENBL_PIN  7  // D7 - MOT_ENBL (Driver Enable)
#define MOT_DIR_PIN   8  // D8 - MOT_ROT_DIR (Rotation Direction)
#define ENC_CS_PIN    9  // D9 - ENC_NCS (AksIM-2 SPI Chip Select)
#define MOT_RUN_PIN   10 // D10 - MOT_RUN (Run/Stop Line)

// Hardware SPI Pins on Arduino Nano:
// D11 = MOSI, D12 = MISO, D13 = SCK

// --- SETTINGS ---
const int targetMotorSpeed = 51; // Constant PWM speed (0-255)

// --- OBJECTS & VARIABLES ---
TinyGPSPlus gps;
SoftwareSerial imuSerial(IMU_RX_PIN, IMU_TX_PIN); // RX = Pin 5, TX = Pin 4

volatile unsigned long lastPPSMillis = 0;
volatile bool ppsTriggered = false;

unsigned long lastEncoderMillis = 0;
bool motorRunning = true;

// ISR for PPS Interrupt on D2
void ppsHandler() {
    lastPPSMillis = millis();
    ppsTriggered = true;
}

void setup() {
    // Standard Hardware Serial for Debugging / Commands
    Serial.begin(115200);
    
    // Software Serial for IMU Communication (via MAX3232)
    imuSerial.begin(9600);
    
    // PPS Interrupt Setup
    pinMode(IMU_SYNC_PIN, INPUT);
    attachInterrupt(digitalPinToInterrupt(IMU_SYNC_PIN), ppsHandler, FALLING);

    // Encoder SPI Setup
    pinMode(ENC_CS_PIN, OUTPUT);
    digitalWrite(ENC_CS_PIN, HIGH);
    SPI.begin();

    // Motor Controller Pins Setup
    pinMode(MOT_PWM_PIN, OUTPUT);
    pinMode(MOT_ENBL_PIN, OUTPUT);
    pinMode(MOT_DIR_PIN, OUTPUT);
    pinMode(MOT_RUN_PIN, OUTPUT);
    pinMode(MOT_FAULT_PIN, INPUT);

    // Initial Motor State Setup
    digitalWrite(MOT_DIR_PIN, LOW);   // Set default direction
    digitalWrite(MOT_ENBL_PIN, HIGH); // Enable controller bridge
    digitalWrite(MOT_RUN_PIN, HIGH);  // Set Run active
    analogWrite(MOT_PWM_PIN, targetMotorSpeed);
    
    Serial.println(F("System Initialized. Commands: 'stop', 'go'."));
}

uint32_t readEncoder() {
    SPI.beginTransaction(SPISettings(4000000, MSBFIRST, SPI_MODE0));
    digitalWrite(ENC_CS_PIN, LOW);
    
    uint32_t b1 = SPI.transfer(0x00);
    uint32_t b2 = SPI.transfer(0x00);
    uint32_t b3 = SPI.transfer(0x00);
    
    digitalWrite(ENC_CS_PIN, HIGH);
    SPI.endTransaction();

    return (b1 << 16) | (b2 << 8) | b3;
}

void printfTime(int h, int m, int s, unsigned long ms) {
    if (ms > 999) ms = 999;
    char buf[25];
    sprintf(buf, "%02d:%02d:%02d.%03lu", h, m, s, ms);
    Serial.println(buf);
}

void loop() {
    // 1. Process Serial Data from IMU
    while (imuSerial.available() > 0) {
        gps.encode(imuSerial.read());
    }

    // 2. Handle PPS Event Flag Safely
    if (ppsTriggered) {
        ppsTriggered = false;
        Serial.println(F("[SYNC] PPS Edge Detected"));
    }

    // 3. Serial Command Processing
    if (Serial.available()) {
        String cmd = Serial.readStringUntil('\n');
        cmd.trim();
        
        if (cmd.equalsIgnoreCase("stop")) {
            motorRunning = false;
            digitalWrite(MOT_RUN_PIN, LOW);   // Disable output drive
            analogWrite(MOT_PWM_PIN, 0);
            Serial.println(F(">>> MOTOR STOPPED"));
        } 
        else if (cmd.equalsIgnoreCase("go")) {
            motorRunning = true;
            digitalWrite(MOT_RUN_PIN, HIGH);  // Resume output drive
            analogWrite(MOT_PWM_PIN, targetMotorSpeed);
            Serial.println(F(">>> MOTOR RESUMED"));
        }
    }

    // 4. Check for Motor Controller Faults
    if (digitalRead(MOT_FAULT_PIN) == HIGH) {
        // Adjust polarity based on Faulhaber SC2804S fault pin logic (active HIGH/LOW)
        // Serial.println(F("WARNING: Motor Controller Fault Pin Triggered!"));
    }

    // 5. 100Hz Logging Loop (10ms interval)
    if (millis() - lastEncoderMillis >= 10) {
        lastEncoderMillis = millis();
        
        uint32_t rawEncoder = readEncoder();
        unsigned long offset = millis() - lastPPSMillis;
        
        Serial.print(F("ENC: "));
        Serial.print(rawEncoder);
        Serial.print(F(" | UTC: "));
        
        if (gps.time.age() < 2000 && gps.time.isValid()) { 
            printfTime(gps.time.hour(), gps.time.minute(), gps.time.second(), offset);
        } else {
            Serial.println(F("NO TIMING DATA"));
        }
    }
}

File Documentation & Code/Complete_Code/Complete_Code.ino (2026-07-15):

#include <TinyGPS++.h>
#include <SoftwareSerial.h>
#include <SPI.h>

// --- PINS ---
#define PPS_PIN   2   
#define GPS_RX    4   
#define GPS_TX    5   
#define ENC_CS    9   
#define MTR_SPD   6   
#define MTR_DIR   8   
#define MTR_EN    10  

// --- SETTINGS ---
const int bitResolution = 17; 
const int targetMotorSpeed = 51; // Constant speed when running

// --- VARIABLES ---
TinyGPSPlus gps;
SoftwareSerial gpsSerial(GPS_RX, GPS_TX);

volatile unsigned long lastPPSMillis = 0;
unsigned long lastEncoderMillis = 0;
bool motorRunning = true; // Track state for Stop/Go

void ppsHandler() {
    lastPPSMillis = millis();
     Serial.println("PPS Detected");
}

void setup() {
    Serial.begin(115200);
    gpsSerial.begin(9600);
    
    pinMode(PPS_PIN, INPUT);
    attachInterrupt(digitalPinToInterrupt(PPS_PIN), ppsHandler, FALLING);

    // SPI Setup for AksIM-2
    pinMode(ENC_CS, OUTPUT);
    digitalWrite(ENC_CS, HIGH);
    SPI.begin();

    // Motor Setup
    pinMode(MTR_SPD, OUTPUT);
    pinMode(MTR_DIR, OUTPUT);
    pinMode(MTR_EN, OUTPUT);
    
    // Initial Start
    digitalWrite(MTR_EN, HIGH);
    analogWrite(MTR_SPD, targetMotorSpeed);
    
    Serial.println(F("System Ready. Type 'stop' to pause, 'go' to resume."));
}

uint32_t readEncoder() {
    SPI.beginTransaction(SPISettings(4000000, MSBFIRST, SPI_MODE0));
    digitalWrite(ENC_CS, LOW);
    
    uint32_t b1 = SPI.transfer(0x00);
    uint32_t b2 = SPI.transfer(0x00);
    uint32_t b3 = SPI.transfer(0x00);
    
    digitalWrite(ENC_CS, HIGH);
    SPI.endTransaction();

    return (b1 << 16) | (b2 << 8) | b3;
}

void loop() {
    // 1. GPS Processing
    while (gpsSerial.available() > 0) {
        gps.encode(gpsSerial.read());
    }

    // 2. Stop/Go Logic
    if (Serial.available()) {
        String cmd = Serial.readStringUntil('\n');
        cmd.trim(); // Remove whitespace
        
        if (cmd.equalsIgnoreCase("stop")) {
            motorRunning = false;
            digitalWrite(MTR_EN, LOW);
            Serial.println(F(">>> MOTOR STOPPED"));
        } 
        else if (cmd.equalsIgnoreCase("go")) {
            motorRunning = true;
            digitalWrite(MTR_EN, HIGH);
            analogWrite(MTR_SPD, targetMotorSpeed);
            Serial.println(F(">>> MOTOR RESUMED"));
        }
    }

    // 3. 100Hz Logging Loop
    // 3. 100Hz Logging Loop
    if (millis() - lastEncoderMillis >= 10) {
        lastEncoderMillis = millis();
        
        // ... (Your encoder reading logic) ...

        unsigned long offset = millis() - lastPPSMillis;
        
        Serial.print(F(" | UTC:"));
        
        // Bypass the validity check to see what the SBG is actually sending
        // Check gps.time.age() to make sure we are getting data at all
        if (gps.time.age() < 2000) { 
            printfTime(gps.time.hour(), gps.time.minute(), gps.time.second(), offset);
        } else {
            Serial.println(F("NO SERIAL DATA"));
        }
    }
}

void printfTime(int h, int m, int s, unsigned long ms) {
    if (ms > 999) ms = 999;
    char buf[20];
    sprintf(buf, "%02d:%02d:%02d.%03lu", h, m, s, ms);
    Serial.println(buf);
}

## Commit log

2026-07-15 Engineering Data
    [Electronics.csv, Electronics.kicad_pcb, Electronics.kicad_sch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]
2026-07-15 new gearsystem calc
